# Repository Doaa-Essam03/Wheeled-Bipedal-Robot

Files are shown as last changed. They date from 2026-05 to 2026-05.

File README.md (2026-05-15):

# Two-Wheeled Self-Balancing Wheel-Legged Robot
**Department of Mechatronics Engineering - Control Systems I**

---

## 📖 Project Overview
This project involves the development of a hybrid locomotion system that combines the high maneuverability of wheeled rovers with the terrain adaptability of bipedal kinematics. By integrating two legs with wheeled feet, the robot can perform height adjustments, X-Y planar navigation, and obstacle avoidance while maintaining vertical equilibrium. The dynamic modeling is based heavily on a four-link geometric-dynamic coupling approach, effectively merging a dual-wheel inverted pendulum with a variable-height linkage mechanism.

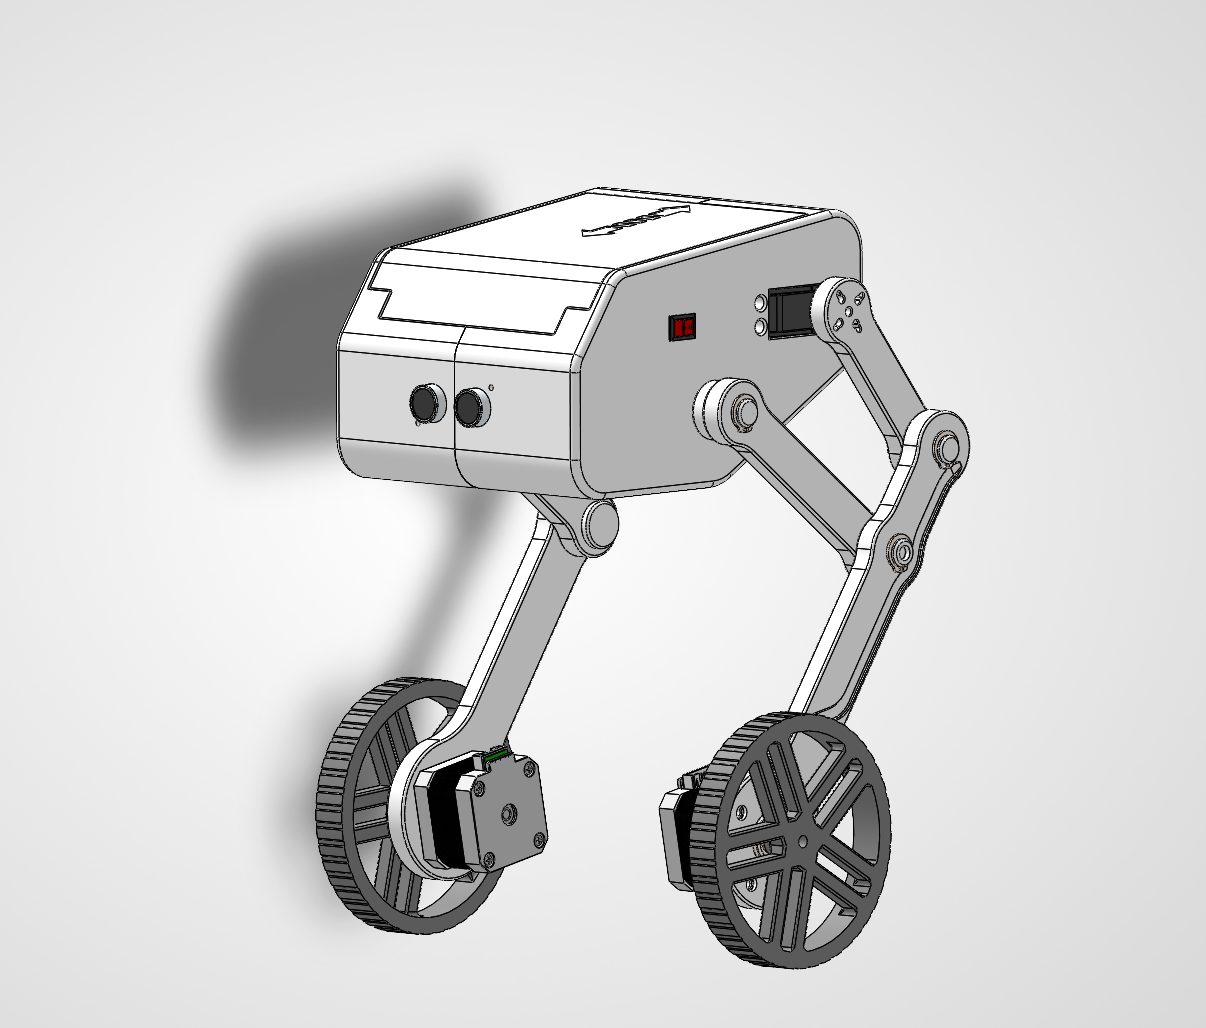
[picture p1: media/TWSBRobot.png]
Assembled Robot

*Figure 1: The fully assembled Two-Wheeled Self-Balancing Wheel-Legged Robot.*

---

## ⚙️ System Architecture
The project is divided into four main engineering pillars:

* **Mechanical Design:** A 2-DOF per leg assembly designed in SolidWorks, optimized for a low Center of Mass (CoM) and minimal inertia. Actuation is handled by NEMA 17 Stepper motors for wheel drive/X-Y motion and Servo motors for leg articulation.
* **Mathematical Modeling:** Derivation of the system's equations of motion, resulting in a non-linear state-space model that decouples the dual-wheel inverted pendulum from the four-link kinematics.
* **Control Engineering:** Implementation of a nested loop control architecture:
    * **Inner Loop:** Proportional-Derivative (PD) control for leg height adjustment and Virtual Model Control (VMC) for joint torque mapping.
    * **Outer Loop:** Linear Quadratic Regulator (LQR) for optimal tilt stabilization and spatial trajectory tracking.
* **Embedded Systems:** Built around an Arduino Nano/ESP32 architecture, featuring real-time sensor fusion using an MPU6050 IMU for attitude estimation. 

---

## 🧠 Control Strategy & Mathematical Modeling
Due to the nonlinear and strongly coupled characteristics of wheeled bipedal robots, developing an accurate mathematical model is critical. 

### State-Space Representation
To design the LQR controller, the system was linearized around the upright equilibrium point ($\theta \approx 0$). 

**4-State Baseline Model (Longitudinal Motion):**
Handles forward/backward displacement and pitch stabilization.

$$X_4 = [x, \dot{x}, \theta, \dot{\theta}]^T$$

**6-State Advanced Model (Spatial Motion):**
Integrates differential drive kinematics to actively command asymmetric torque for yaw (steering) without destabilizing the pitch axis.

$$X_6 = [x, \dot{x}, \theta, \dot{\theta}, \delta, \dot{\delta}]^T$$

**Objective:**
Minimize the cost function $J$ to find the optimal gain matrix $K$, balancing the penalty on pitch deviation against excessive torque demands:
$$J = \int_{0}^{\infty} (X^T Q X + u^T R u) dt$$

### Polynomial Fitting & Real-Time Gain Scheduling
A fundamental challenge of this robot is that its center of mass ($l_w$) and rotational inertia continuously change as the leg linkages flex and extend. Continuously solving the discrete Algebraic Riccati Equation (DARE) for the LQR controller is computationally expensive and would cause severe loop latency on an embedded microcontroller.

To solve this, an offline **Polynomial Gain Scheduling** architecture was developed:
1.  **Offline MATLAB Evaluation:** The optimal feedback gain matrices ($K$) were pre-calculated across the entire operational range of the upper servo angle ($\theta_1$).
2.  **Curve Fitting:** A least-squares fitting algorithm modeled the relationship between $\theta_1$ and each gain value into second-order polynomials:
    $$k_i(\theta_1) = a_i\theta_1^2 + b_i\theta_1 + c_i$$
3.  **Real-Time Execution:** During live operation, the microcontroller simply reads the current servo angle and evaluates these polynomials to instantly update the $K$ matrix coefficients. This reduces complex matrix calculus to basic arithmetic, enabling an ultra-fast control frequency of 200 Hz.

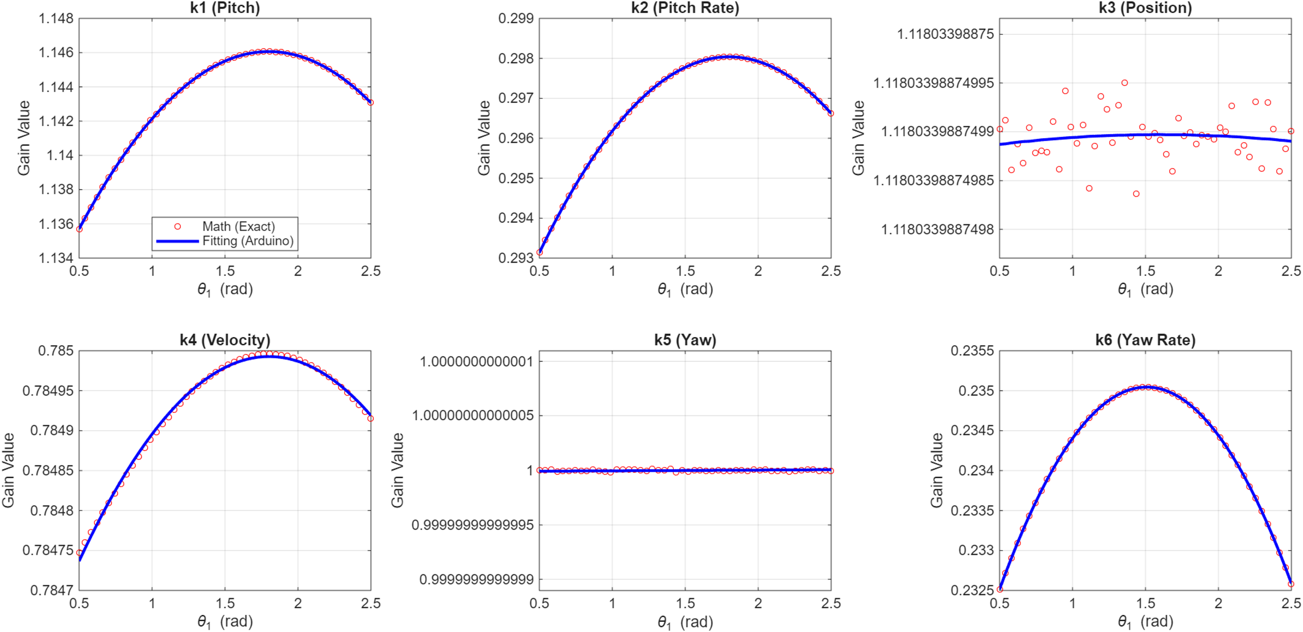
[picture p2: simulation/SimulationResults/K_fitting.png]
Validation of K Matrix Gains

*Figure 2: MATLAB polynomial curve fitting vs. exact mathematical $K$ matrix gains across the operational servo angles.*

---

## 📁 Repository Navigation
* **/hardware:** SolidWorks `.SLDASM` files, 3D printing STL files.
* **/simulation:** `.slx` Simulink models (including Simscape Multibody environments) and MATLAB kinematics/fitting scripts.
* **/firmware:** Source code for the microcontroller (written in C++), featuring I2C MPU6050 drivers, offline polynomial arrays, and the high-frequency LQR/PD control loops.
* **/docs:** Reference papers, the final project report, and the mathematical derivation of the plant.
* **/media:** Videos and pictures of the physical testing.

---

## 🎯 Key Technical Features
* **Dynamic Balancing:** Active rejection of external gravity and impulse forces via continuous LQR state-feedback.
* **Variable Height & Gain Scheduling:** Offline polynomial curve fitting ensures the LQR controller dynamically adapts to shifting inertia and CoM as the robot squats or stands.
* **Virtual Model Control (VMC):** Bridges multi-body mechanics to actuator joint spaces, calculating required support forces without injecting disruptive disturbances into the primary balancing loop.
* **Sim-to-Real Verification:** Validated 3D multi-body pitch stabilization inside a high-fidelity Simscape physical environment prior to hardware deployment.

---

## 👥 Team Members
* **Doaa Essam, Amr Mohamed, Alyaa Mohamed, Abdelrahman Hatem, Esraa Mohamed, Mina Sameh**

### Under supervision of: 
* **Assoc. Prof. Dr. Shuaiby Mohamed**
* **Faculty of Engineering, Assiut University (2025-2026)**

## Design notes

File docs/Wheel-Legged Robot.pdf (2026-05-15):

# Wheel-Legged Robot

## MET 331: Automatic Control 1

## Team Members

Amr Mohamed | Doaa Essam
Abdelrahman Hatem | Esraa Mohamed
Mina Sameh | Alyaa Mohamed

## Supervisor

## Assoc. Prof. Dr. Shuaiby Mohamed

## Mechatronics Engineering Department Faculty of Engineering Assiut University

2025-2026

II

### 1 Table of Contents

1 | Table of Contents | II
2 | Table of Symbols | V

III

IV

Table of Figures

V

### 2 Table of Symbols

Table 1. Parameter definitions of inverted pendulum model.

Symbol | Meaning | Unit
M | Body mass | kg
m | Wheel mass | kg
l | Distance from body center of mass to wheel center | m
r | Wheel radius | m
D | Distance between left and right wheels | m
g | Gravitational acceleration | m/s²
θ, θ̇, θ̈ | Machine pitch angle, angular velocity, angular acceleration | rad, rad/s, rad/s²
T_L, T_R | Driving torque of the wheel | N·m
NL, NR, PL, PR | Force between the body and the wheel in the x and y directions | N
F_L, F_R | Friction between the wheel and the ground | N
xL, xR, ẋL, ẋR, ẍL, ẍR | Wheel displacement, velocity, acceleration | m, m/s, m/s²
ωL, ωR, ω̇L, ω̇R | Wheel rotation angular velocity and acceleration | rad/s, rad/s²
I | Wheel moment of inertia | kg·m²
Jx, Jy, Jz | Moment of inertia of the body around the x, y, z axes | kg·m²
δ, δ̇, δ̈ | Course angle, angular velocity, angular acceleration | rad, rad/s, rad/s²

Table 2. Parameter definitions of the wheel-legged robot model.

Symbol | Meaning | Unit
l1, l2, l3, l23 | Length of the corresponding rod | m
l4 | Distance between the joints | m
l5 | Distance from the intersection point of the upper joint to the lower lever | m
lleg | Pendulum height | m
θ1 | Angle between bar l2 and the horizontal axis | rad
θ2 | Angle between auxiliary connecting rod l4 and l5 | rad
θ3 | Angle between auxiliary connecting rod l5 and l23 | rad
θ4 | Angle between bar l1 and the horizontal axis | rad
θ5 | Angle between bar l23 and the horizontal axis | rad
θ6 | Angle between bar l3 and the horizontal axis | rad
Ldesired | Desired leg length | m
xc2, xc1, xc3, xc23 | Vertical coordinates of the center of mass of the connecting rod | m
L0 | Height of the total center of gravity of the system | m
lw | Height of the center of gravity of the pendulum | m
R | Drive wheel radius | m
mw | Drive wheel mass | kg
mb | Body mass | kg
ml | Pendulum mass | kg
mp | Total system mass | kg
L1 | Distance from center of gravity to wheel axle | m
Iw1 | Drive wheel moment of inertia | kg·m²
Ip1 | Moment of inertia of a pendulum | kg·m²
N | Normal force | N
P | Combined force of gravity and acceleration | N
T | Driving torque | N·m

### 3 Introduction

### 3.1 Evolution of Mobile Robotics The Wheel-Legged Paradigm

For intelligent mobile robots, the Wheel-Legged Robot is dealt with as high maneuverability, easy transformation, and

efficient animal-based design robots. The evolution of these platforms seeks to bridge the gap between the speed of

traditional wheeled rovers and the terrain adaptability of legged variants.

### 3.2 Project Scope and Academic Context

This project enabled us in integrating variable subsystems in one project being such impressive Mechatronic system

enabling. From Mathematical equations, Mechanical design, Embedded system integration, and Control system design,

the scope covers the full lifecycle of mechatronic product development.

### 4 Problem Statement

Developing a unified wheel-legged robot is dealt with as a complex mechatronic struggle where the gap between

theoretical mathematical models and physical embedded hardware often results in poor system performance. The non-

linear multi-body dynamics inherent in combining a four-bar linkage with an inverted pendulum create significant

computational bottlenecks for standard embedded controllers.

This project enabled us in overcoming the difficulty of synchronizing mechanical link dynamics with real-time control

algorithms being a fully integrated mechatronic achievement. From mechanical design complexities, mathematical

modeling errors, embedded integration hurdles, and control system instability.

### 5 Project Objectives

For achieving high maneuverability and stability, this project aims in developing advanced hybrid control systems. This

requires structural optimization of the linkage mechanisms, mathematical optimization through polynomial fitting to

handle dynamic shifts, and scaling the control architecture to manage varied actuators.

This project enabled us in creating accurate mathematical models being such a precise mechatronic integration. From

LQR for balance, PD for height control, and Fitting Techniques for real-time CoM prediction with considering applying

these strategies in a real-world plant.

### 6 Mechatronic System Design

### 6.1 Mathematical Modeling for the system

Treating physical plant as two subsystems: height subsystem or four bar linkage to model the variation in height and leg

mechanism, and inverted pendulum subsystem to model the balancing function of the robot and its motion.

### 6.2 Control System Configuration

Based on mathematical model made and out understanding of the physical functions needed, we made the control

strategy to be in two systems: PD control to manage height, LQR control to manage balance and motion.

### 6.3 Physical system design (Mechanical)

Here we created the physical plant to be established in real-world. The plant design must fit configurations made in

mathematical model from masses and dimensions.

### 6.4 Embedded Hardware in Robot

The physical plant to be actuated we need actuators to do the functions needed, sensors to close the control loop, and

controller itself to manage all that.

### 6.5 Mechanical Design

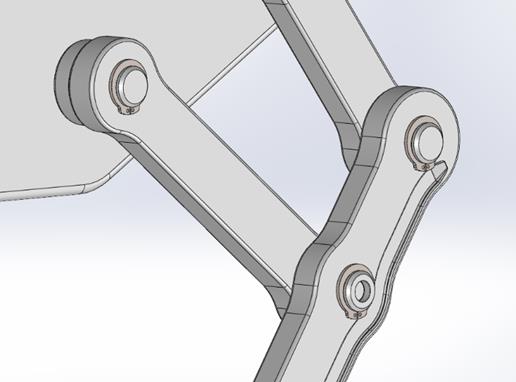
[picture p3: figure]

Figure 1 linkage fixdiation

The design is made mainly to be easy in manufacturing and assembly.
From selecting 3D printed PLA to be the material used, we customized the design on it.
The design is easy in assembly by using snap-rings, interference fit assembly, and easy pin usage with respect of suitable dimensions.

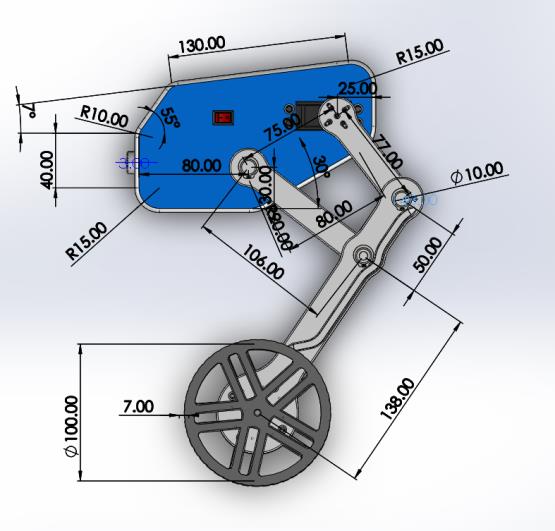
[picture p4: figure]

Figure 2 Side View

Figure 4 3d printed part

Figure 3 side view of linkage

Figure 5 Assembled robot

Figure 6 Exploded view

Also for wire management, we made a slot in stepper-motor’s link to act like a duct for wires to manage in.

In wheel, it’s critical area where we need to decrease friction between wheel and link, and increase friction in suitable area between wheel and ground to keep balance and stable and move right.
We designed the wheel to have a good friction surface with ground, ribs are made to avoid stresses on hip and make two direction of reaction torques from ground to wheel what make a passive balance.

Also considered bearing assembly between wheel and motor’s shaft to keep smooth motion.

### 6.6 Electronic Hardware and Sensor Integration

The robot hardware consists of sensing, control, and actuation components integrated together to achieve self-

balancing operation.

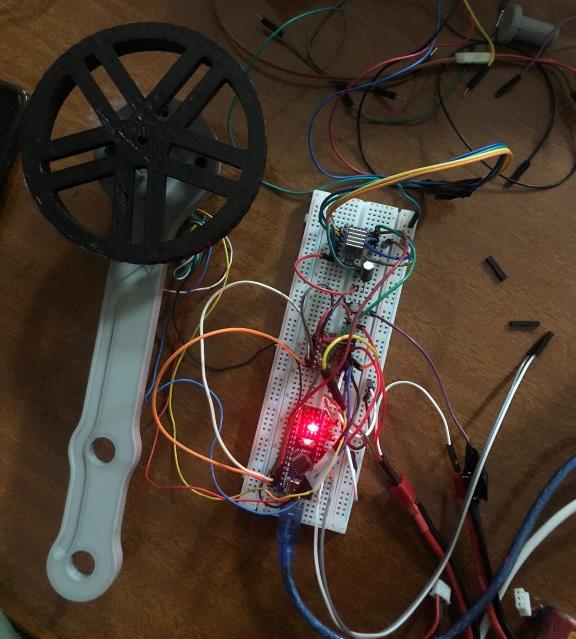
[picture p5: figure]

Figure 7 Testing stepper motor

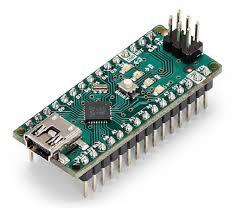
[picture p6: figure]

### 6.6.1 Central Processing Unit (ESP32)

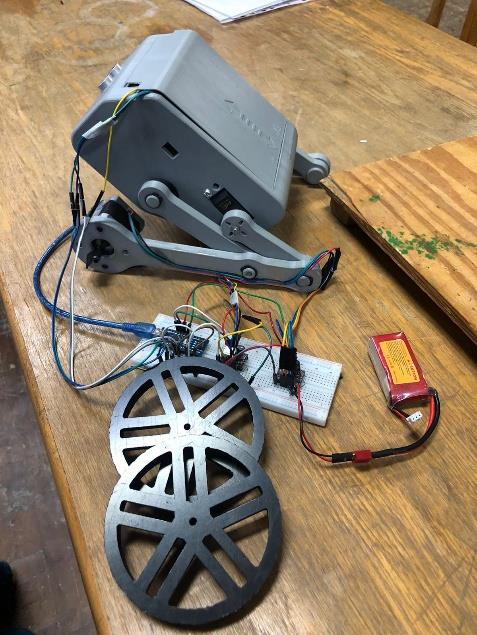
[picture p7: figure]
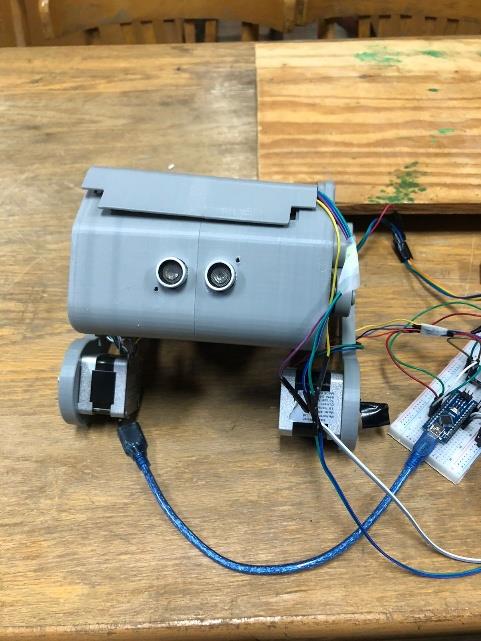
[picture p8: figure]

The main controller used in the system is the Arduino Nano, which is responsible for

processing sensor data and generating control signals for the motors.

An ESP32 module was also considered for future development to provide wireless

communication, remote monitoring, and real-time data transmission capabilities.

### 6.6.2 Attitude Estimation (MPU6050 IMU & Filtering)

The robot uses the MPU6050 inertial measurement unit to measure the robot

orientation and angular velocity.

The sensor communicates with the Arduino Nano using the I2C protocol

through the SDA and SCL pins.

The MPU6050 sensor is connected to the Arduino Nano using the I2C

communication protocol. The SDA pin of the MPU6050 is connected to pin A4

of the Arduino Nano, while the SCL pin is connected to pin A5. The sensor is

powered using the 5V and GND pins of the Arduino. Through this connection,

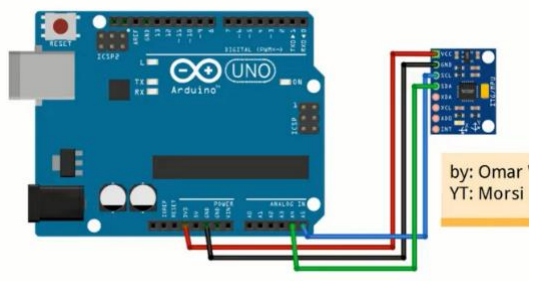
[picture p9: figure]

Figure 8 MPU wiring

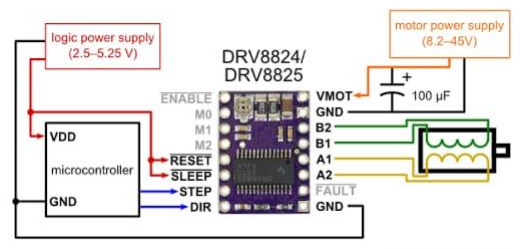
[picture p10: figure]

Figure 9 stepper driver wiring the microcontroller continuously receives accelerometer and gyroscope measurements required for estimating the

robot orientation and angular velocity

### 6.6.3 Ultrasonic

Additionally, an ultrasonic sensor was prepared for future implementation in obstacle detection and

environmental interaction. The sensor has not yet been integrated into the software because the current stage of

the project focuses mainly on achieving stable balancing performance.

### 6.6.4 Actuation System (Stepper Motors & Servos)

### 6.6.4.1 Stepper motors

Two stepper motors are used as the main actuation system for balancing

and movement. Each motor is driven using a DRV8825 Stepper Motor

Driver driver module, which receives STEP and DIR signals from the

microcontroller to control motor speed and rotation direction with high

precision.

### 6.6.4.2 Servo motors

The system also includes two servo motors intended for adjusting the robot leg configuration and varying the

effective pendulum length during operation. However, in the current implementation, the leg length is assumed

to be fixed; therefore, the servo motors are not yet integrated into the code in arduino .

### 6.6.5 Power Management (LiPo Battery Weight Reduction)

A high-discharge Lithium-Polymer (LiPo) battery pack was selected to power the system instead of traditional heavy

batteries, due to its superior energy density and lightweight profile. This choice minimized the global weight of the

prototype and successfully delivered the high current spikes required by the NEMA 17 stepper motors during rapid

balancing corrections, while placing it at the bottom of the chassis base successfully lowered the center of mass to

enhance structural stability.

### 7 Mathematical Modelling

The wheeled bipedal robot is a complex nonlinear multiple-input multiple-output system, which regards the robot as a

combination of left and right legs, left and right wheels, plus the body, and left and right symmetry, so an idealized

setting can be made.

The robotic dynamic model is decomposed into wheel motion and leg motion. The wheel subsystem, responsible for

linear locomotion and steering, is simplified as a two-wheel inverted pendulum model. The leg subsystem employs a

four-bar linkage mechanism to achieve jumping, full-body height adjustment, and adaptive locomotion on uneven

terrain. By focusing on analyzing the dynamic model of the four-bar linkage motion, the originally coupled complex

model is streamlined. As shown in Figure 1, this decoupling strategy simplifies the design process while retaining critical

functionalities, thus enabling efficient control of the robot’s hybrid mobility modes.

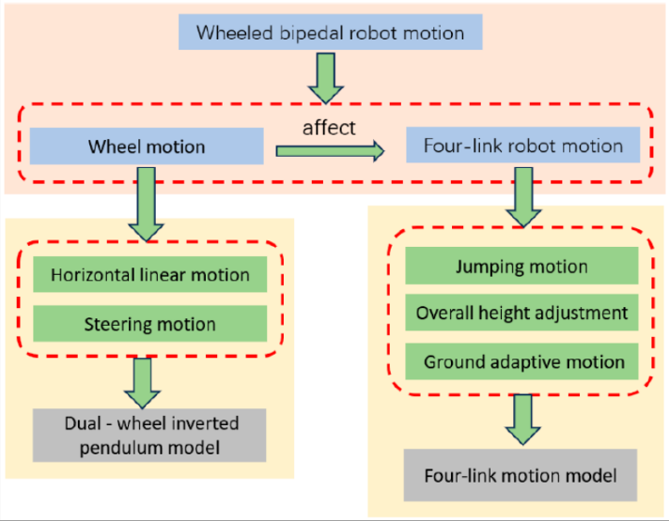
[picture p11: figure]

Figure 10 modeling systems

### 7.1 Dual-Wheel Inverted Pendulum Model

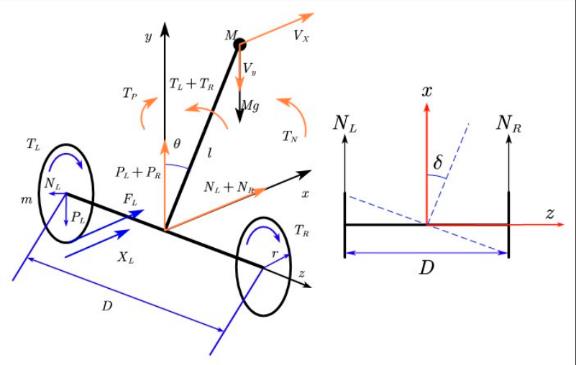
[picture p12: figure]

The mass of the body is equivalently concentrated in the position of the center of mass. Ignoring the effect of the leg motion on the wheeled movement and the mass of the four links, the driving wheels are in non-slip rolling friction with the ground. Therefore, the four-link wheel-legged robot can be equivalently simplified into a two-wheeled inverted pendulum model with variable rod length , see Figure 2 and Table 1.

### 7.1.1 The equations of Inverted Pendulum

### 7.1.1.1 Planar Linearization and Baseline Dynamics

To design a linear optimal controller such as the Linear Quadratic Regulator (LQR), the highly non-linear equations of motion derived via the Euler-Lagrange framework must be linearized around the upright equilibrium point. When the pitch inclination of the main body ($\theta$) is small (θ ≈ 0$), the small-angle approximation can be applied safely. Under these assumptions, higher-order differential terms are neglected, and the trigonometric variables are linearized as follows

Figure 11 Inverted Pendulum Model

cos θ ≈ 1, sin θ ≈ θ, θ

2̇ ≈ 0

Applying these conditions to the continuous planar dynamics yields the coupled, linearized differential equations governing longitudinal displacement (x) and body pitch (θ) [1]:

(M + 2m +

2Iw
r

2

) ẍ=

TL + TR
r

− Mlθ̈

(Jz + Ml

2

)θ̈= Mglθ − Mlẍ− (TL + TR)

These coupled relations serve as the direct mathematical basis for the 4-state state-space block

(X4 = [x, ẋ, θ, θ̇]

T
)

constructed within the MathWorks Simulink modeling workspace to evaluate initial straight-line balancing performance.

### 7.1.1.2 Steering Kinematics and Yaw Modeling

To achieve full 3D planar mobility, differential steering capabilities must be integrated alongside the longitudinal balancing routines. By sorting the mechanical equations of constraint across the transverse horizontal frame, the uncoupled dynamic equation governing the steering yaw angle ($δ$) is formulated as follows [1]:

δ̈=

TL − TR
r (mD +

ID
r

2 +

2Jy
D

)

This yaw relation is mathematically superimposed over the planar balancing matrix to build out the full 6-state spatial LQR vector ($X6 = [x, ẋ, θ, θ̇

, δ, δ̇]

T
$). Within Simulink, this decoupled torque relationship (ΔT = TL − TR$) is utilized by the controller to actively adjust steering headings without injecting unstable oscillations into the main pitch axis ($θ$).

Inverted pendulum model in Simulink

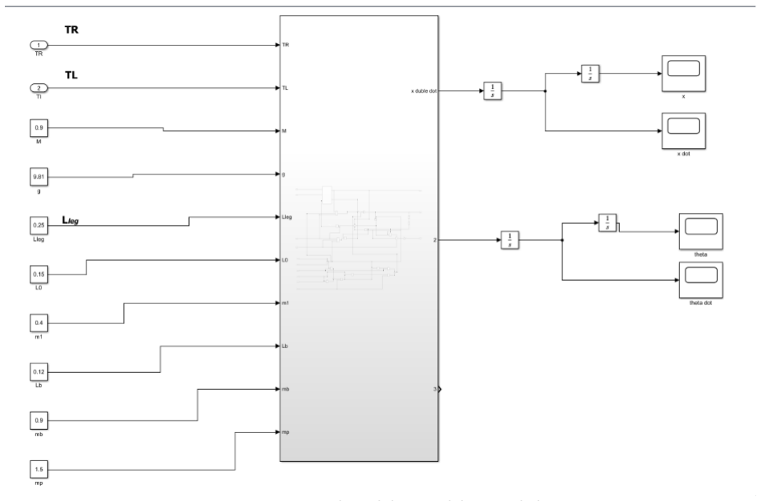
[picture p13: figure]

Figure12 Inverted pendulum model in Simulink

### 7.1.2 Four-Link Motion Model

The whole machine is symmetrical on the left and right, the kinematics of the four-link structure of the left leg are analyzed in detail see figure , and the relevant parameters are illustrated in Table 2 .

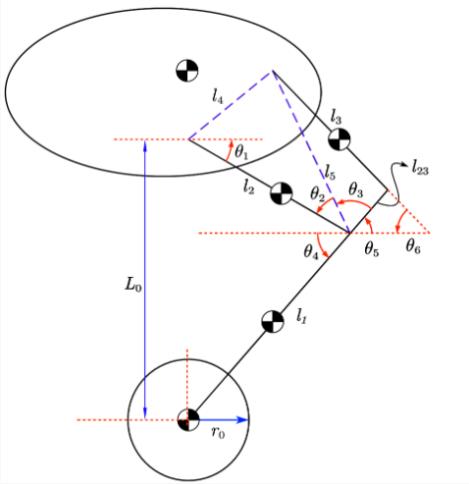
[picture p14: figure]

Figure 12 Four-Link Motion Model

### 7.1.2.1 The equations of Four-Link Mechanism

Given the instantaneous command angle of the joint servo motor θ1, the secondary linkage parameters (θ2, θ3, θ4) and

the final effective leg length ($l_{leg}$) are computed explicitly as follows:

l5 = √l2
2 + l4

2 − 2 ⋅ l2 ⋅ l4 ⋅ cos (θ1 +

π
4

)

θ2 = arcsin(
l4 ⋅ sin (θ1 +

π
4

)

l5

)

θ3 = arccos (
l23

2 + l5

2 − l3
2
2 ⋅ l23 ⋅ l5

)

θ4 = π − θ1 − θ2 − θlleg = l2 ⋅ sin(θ1

) + l1 ⋅ sin(θ4)

### 7.1.2.2 Inverse Kinematics (Leg Length to Angle)

When managing height tracking commands, the target leg length (l{leg}) is transformed back into the required actuator

servo angle (θ1) along with companion configurations (θ5, θ6) via the following inverted expressions:

θ1 = arcsin (

lleg

2 + l2 2 − l1
2
2 ⋅ lleg ⋅ l2

)

θ5 = π − θ4

θ6 = arcsin (
l5 ⋅ sin( 3

)
l3

) − θ4

### 7.1.2.3 Center of Gravity Offset (lw)

The overall vertical center of mass displacement (lw) of the mechanical assembly relative to the wheel rotational hub is obtained directly by subtracting the linkage mass weighted average (Lo) from the total computed leg height:

lw = lleg − L0

Where L0 represents the composite geometric center of gravity distribution across the linkage components (m1, m2, m3, m23):

L0 =

m1 ⋅ xc1 + m2 ⋅ xc2 + m3 ⋅ xc3 + m23 ⋅ xc23 m1 + m2 + m3 + m23

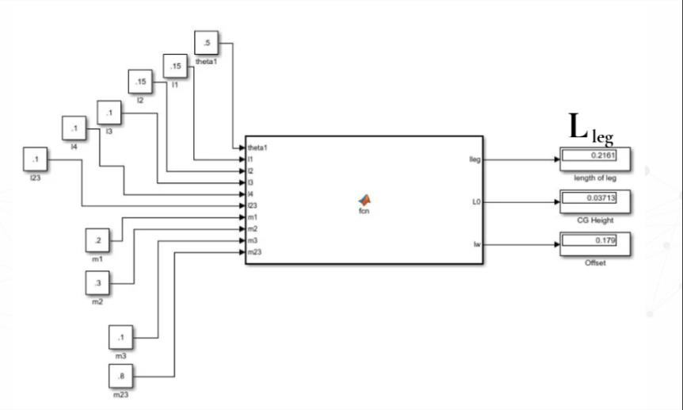
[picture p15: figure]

### 8 Control Strategy

### 8.1 PD control

PD control is used to calculate the external force F0 that needs to be applied on the joint motor. Omitting the I term can

avoid the situation of integral saturation overshooting and improve the dynamic response speed, which is suitable for

highly dynamic scenarios. The integral term will accumulate noise or high-frequency interference, which will lead to

jitter of the control signal, while the differential term has a natural suppression effect on high-frequency noise, and PD

control is more anti-interference.

### 8.1.1 Error Formulation and Controller Optimization [1]

The height controller monitors the instantaneous offset between the calculated leg length (lleg) and the target setpoint (L_{desired}). The geometric tracking error (e)is defined as [1]:

e = lleg + Ldesired

Using this error signal, the restorative control effort (τPID)is processed via a PD loop to drive the vertical tracking error to zero :

τPID = Kpe + Kd

de
dt

### 8.1.2 Gravity Feedforward Compensation [1]

The mass of the physical robot assembly serves as a continuous constant load on the articulated joint actuators. The

vertical ground support force required to hold the chassis is proportional to the total gravitational force (mg). However,

due to the articulation angle of the four-bar linkages, the actual torque seen at the link joint is modulated by its

geometric position. The localized joint-angle effect is captured by introducing a continuous gravity compensation

component (τgravity):

τgravity = mg cos(θ1)

Where cos(θ1

)reflects the instantaneous rotation angle of the joint relative to the gravitational vector. Combining the

dynamic PD response alongside this static feedforward torque yields the final required external joint force command F0

F0 = τgravity + τPID

### 8.2 Virtual Model Control (VMC) and Joint Torque Mapping [1]

To implement the calculated spatial force commands (F0$) using physical hardware, Virtual Model Control (VMC) is

utilized. VMC creates a mathematical bridge between physical multi-body mechanics and actuator joint spaces. This

architecture assumes an ideal "virtual model" (such as a structural spring-damper suspension) exists between the main

chassis frame and the driving wheel hub,

### 8.2.1 Jacobian Formulation and Force Translation [1]

Translating the operational force F0 into a concrete joint motor torque Tjoint requires evaluating the geometric

constraints of the closed four-bar linkage mechanism. By transforming the link angles and tracking segment lengths, the

continuous system mapping is resolved using a localized scalar element of the system Jacobian matrix (J) [1]:

J = l2 cos(θ1

) + l1 cos(θ1 + α + β)

The computed external force (F0) acting from the end-effector endpoint serves as the fundamental input variable for the

virtual model. By applying the principle of virtual work, the geometric parameters and kinematic configurations are

mapped cleanly to the physical actuator via the Jacobian scalar :

Tjoint = F0 J

This VMC framework operates in parallel with the high-speed wheel LQR tracking loops. It allows the ESP32

microcontroller to execute smooth, low-latency crouching, standing, and active landing maneuvers on the physical

hardware without injecting disruptive force disturbances into the primary self-balancing control loops.

### 8.2.2 PD control & Four bar linkage Model in Simulink

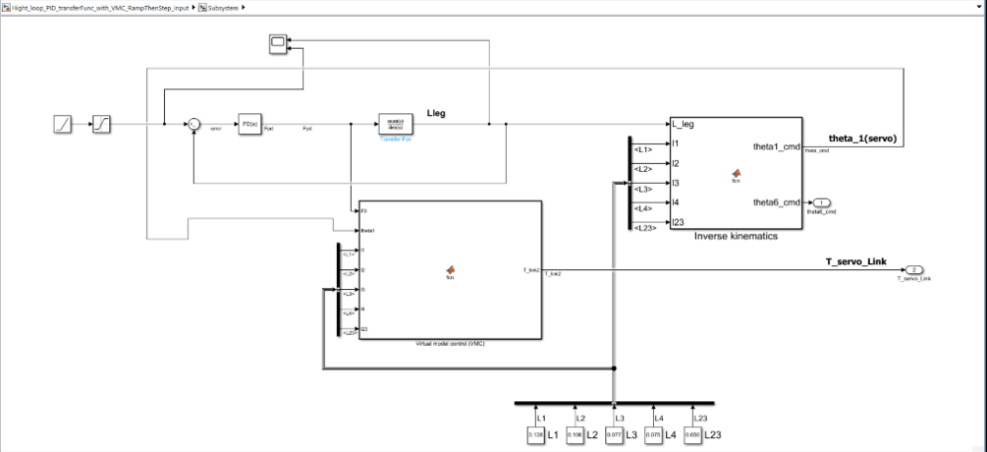
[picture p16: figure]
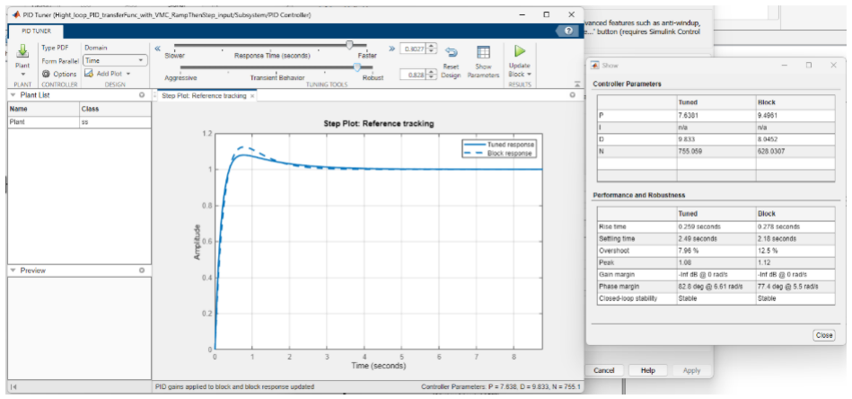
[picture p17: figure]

Figure 13 PD Response

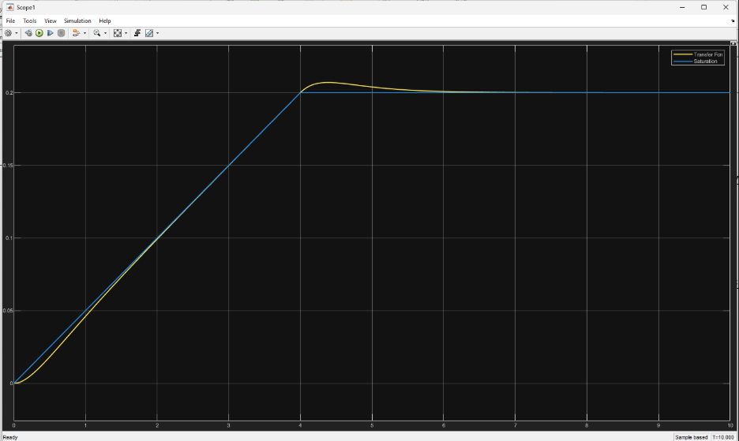
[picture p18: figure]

Figure 14 PD response with ramp mixed step input

### 8.3 LQR with Dynamic Modeling & State-Space Expansion

Due to the nonlinear and strongly coupled characteristics of wheeled bipedal robots, developing an accurate

mathematical model is critical for effective control. The fundamental challenge of the TWSBR is that its center of mass

(COM) and rotational inertia change continuously as the leg linkages flex and extend. To achieve robust balancing and

trajectory tracking, the dynamic equations were derived using the Euler-Lagrange formalism and subsequently linearized

around the upright equilibrium point to form the state-space representation
Ẋ = AX + Bu

Recognizing the need for both longitudinal stability and spatial maneuverability, the control architecture was

incrementally expanded from a planar 4-state model to a comprehensive 6-state model and tested inside MathWorks

Simulink.

### 8.3.1 Baseline 4-State Longitudinal Model (x, ẋ, θ, θ̇)

The initial control framework treated the robot as a variable-length two-wheeled inverted pendulum restricted to purely

longitudinal (forward and backward) motion. The system dynamics were captured using a 4-dimensional State Vector :

X4 = [x ẋ θ θ̇]

T

where xand ẋ represent the longitudinal displacement and velocity of the wheel axle, while θ and θ̇ denote the pitch

angle and pitch angular velocity of the main body, respectively. In this planar configuration, the control input u was

defined as the total symmetric torque applied to both wheels, u = TL + TR

The Linear Quadratic Regulator (LQR) was designed to minimize the cost function J = ∫ (X

TQX + u

TRu)dt ∞
0

, where the

state weight matrix Q heavily penalized deviations in the pitch angle to prevent tipping, and the control weight matrix R

restricted excessive torque demands that could saturate the stepper motors.

This configuration was modeled in Simulink utilizing the native State-Space block to evaluate baseline stabilization and

straight-line displacement tracking.

### 8.3.2 Advanced 6-State Spatial Model (Integration of Yaw δ, δ̇)

While the 4-state model successfully stabilized the robot against gravity, real-world navigation requires active steering.

The model was therefore expanded into a 6-state spatial vector to incorporate differential drive kinematics:

X6 = [x ẋ θ θ̇ δ δ̇]

T

Here, δ and δ̇represent the yaw (heading) angle and yaw rate. To control this expanded system, the input vector was

separated into independent left and right wheel torques:

u = [

TL
TR

]

This decoupling allows the LQR controller to actively command asymmetric torque (TL ≠ TR) to induce a turning

moment around the Z-axis, while simultaneously maintaining the symmetric torque required to keep the inverted

pendulum upright.

This advanced configuration was fully implemented inside a 6-state Simulink block diagram. Virtual reference-tracking

verification was conducted by feeding targeted coordinate trajectories into the controller. The resulting response curves

verified that the 6-state system could successfully execute full planar trajectory following and waypoint target capture

without destabilizing the pitch axis.

Figure 15: LQR with 4

Figure 16 : LQR with 6

### 8.4 Look-up Polynomial Fitting & LQR Gain Scheduling

A critical limitation in embedded mechatronics is the computational bottleneck of solving complex mathematical models

in real-time. Calculating the optimal LQR feedback matrix K requires solving the discrete Algebraic Riccati Equation

DARE. Because the A and B matrices in our state-space model are heavily dependent on the time-varying linkage angle

(θ1

) the optimal K matrix must also change dynamically. However, continuously solving the DARE on an ESP32

microcontroller at a high control frequency (e.g., 200 Hz) would cause severe loop latency. To bypass this, an offline

gain-scheduling architecture was developed.

### 8.4.1 Offline MATLAB Curve Fitting for Kinematics

To eliminate real-time computational overhead, the non-linear geometric and optimal control calculations were shifted

offline. A MATLAB script was developed to sweep through the entire operational range of the upper servo angle

θ1 ∈ [0.5,1.25] rad . For each discrete angular increment, MATLAB evaluated the exact closed-form vector loops to

determine the leg length (lleg) and the vertical center of gravity offset (lw). The script then generated the localized A

and B state-space matrices and solved the DARE to extract the optimal K matrix for that specific posture.

Finally, a least-squares curve fitting algorithm was applied to model the relationship between θ1 and each specific gain

value kiwithin the K matrix. The resulting approximations took the form of second-order polynomials:

ki

(θ1

) = aiθ1

2 + biθ1 + ci

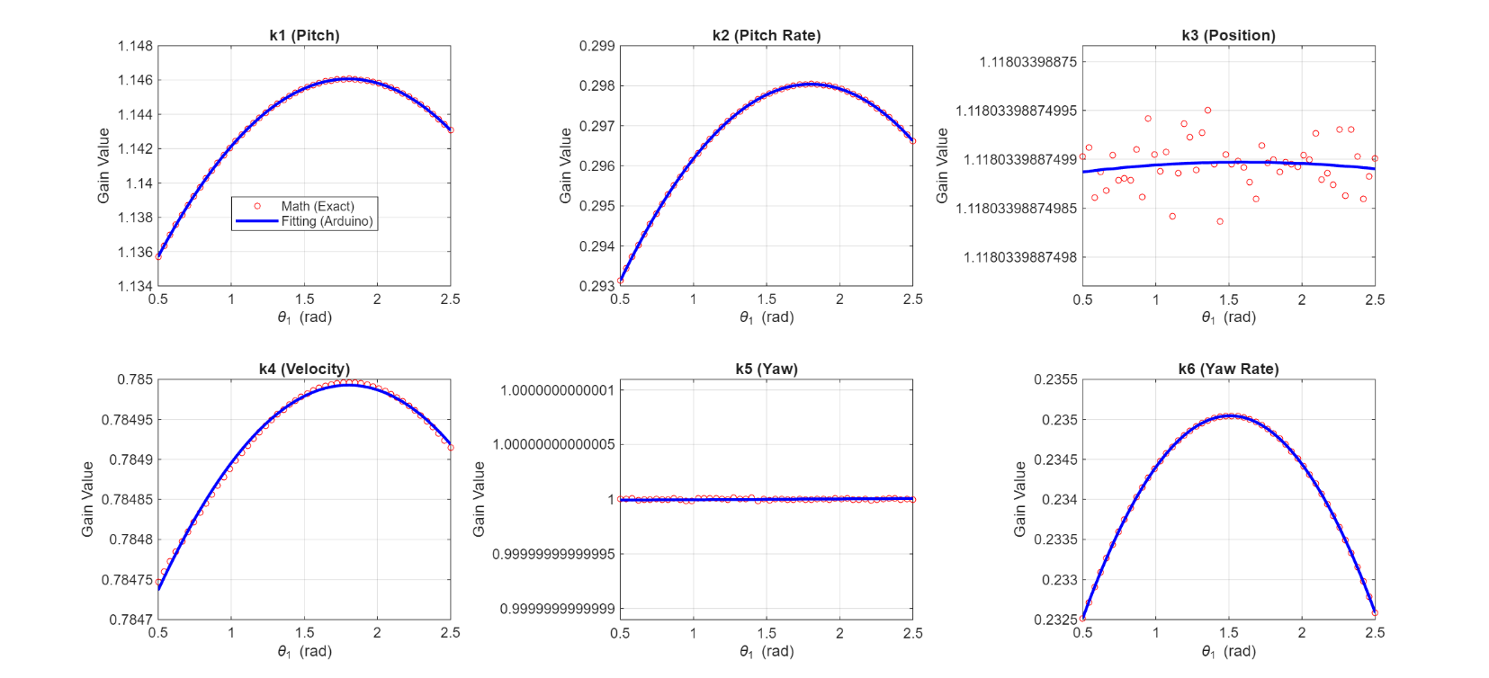
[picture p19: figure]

Figure 17 validation k matrix gains

### 8.4.2 Real-Time LQR Matrix Adjustment

During live operation, the ESP32 executes a highly optimized gain-scheduling routine. By reading the current servo angle

θ1, the microcontroller evaluates the pre-calculated polynomials to instantly update the K matrix coefficients. This approach reduces the complex matrix calculus down to a few basic floating-point multiplications and additions per cycle.

Consequently, the TWSBR seamlessly scales its control authority, applying stiffer gains when standing tall and softer

gains when crouched low—while maintaining an ultra-fast control loop iteration time that prevents instability.

### 9 Simulation and Experimental Results

### 9.1 Simscape Multi-Body Simulation Environment

### 9.1.1 CAD Integration and Virtual Physics Setup

To validate the control algorithms before hardware deployment, a Simscape simulation environment was established.

Rather than importing the highly detailed manufacturing CAD, a simplified CAD assembly was utilized to identify the

primary components, focusing strictly on accurate mass distribution, inertia tensors, and critical dimensions. A global

ground reference was established, and the robot model was linked using appropriate physical joints. This ensured the

virtual model reacted physically accurately to the simulated ground and spatial environment, properly respecting the

laws of inertia, joint friction, and gravity.

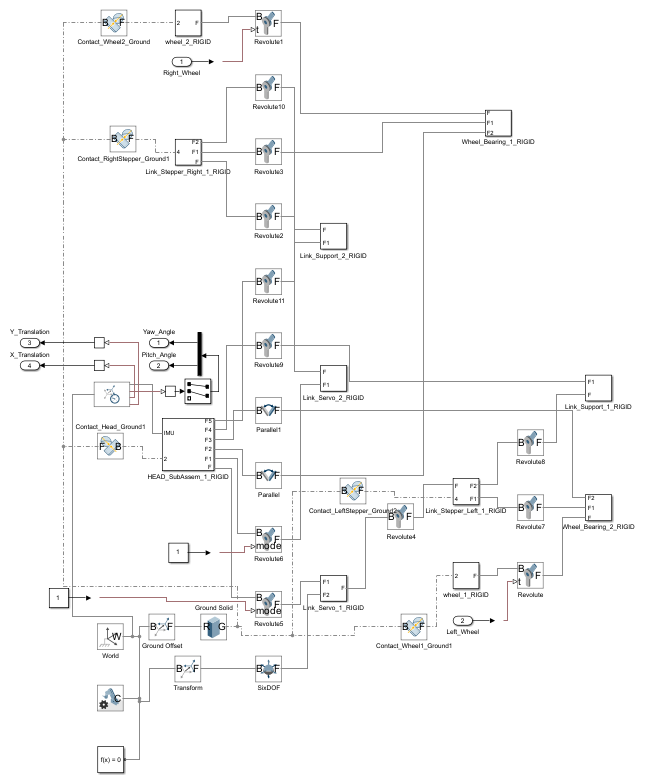
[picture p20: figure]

Figure 18 simscape model

### 9.2 Control Verification

Transitioning directly from mathematical theory to physical hardware carries a high risk of catastrophic failure and

hardware damage. To mitigate this, a high-fidelity virtual environment was constructed by importing the SolidWorks

CAD assembly into MathWorks Simscape Multibody. This setup captures actual material densities, moments of inertia,

and real physical joints, serving as an intermediate stage between ideal block-diagram state-space simulations and

physical reality.

Static Pitch Stabilization (Constant θ1)

The initial simulation phase inside the Simscape physical environment focused entirely on the robot's primary survival

mechanism: active self-balancing. For this verification stage, the servo angle $\theta_1$ was held at a constant value,

fixing the physical four-bar linkages in place. The control loop was structured around feedback sensing blocks acting as

an ideal Inertial Measurement Unit (IMU).In this phase, the LQR tuning process concentrated heavily on the pitch

($\theta$) and pitch rate ($\dot{\theta}$) states to handle balance stabilization. The Simscape model layout integrated

sensory feedback blocks, a closed-loop LQR matrix mixer, and physical rotational actuators on the wheel hubs. The

simulation confirmed that the derived control framework successfully suppressed gravitational tilt errors, achieving

rock-solid upright balance. The collected data plotting curves demonstrated clean convergence back to the zero-pitch

vertical axis following external impulse disturbances.

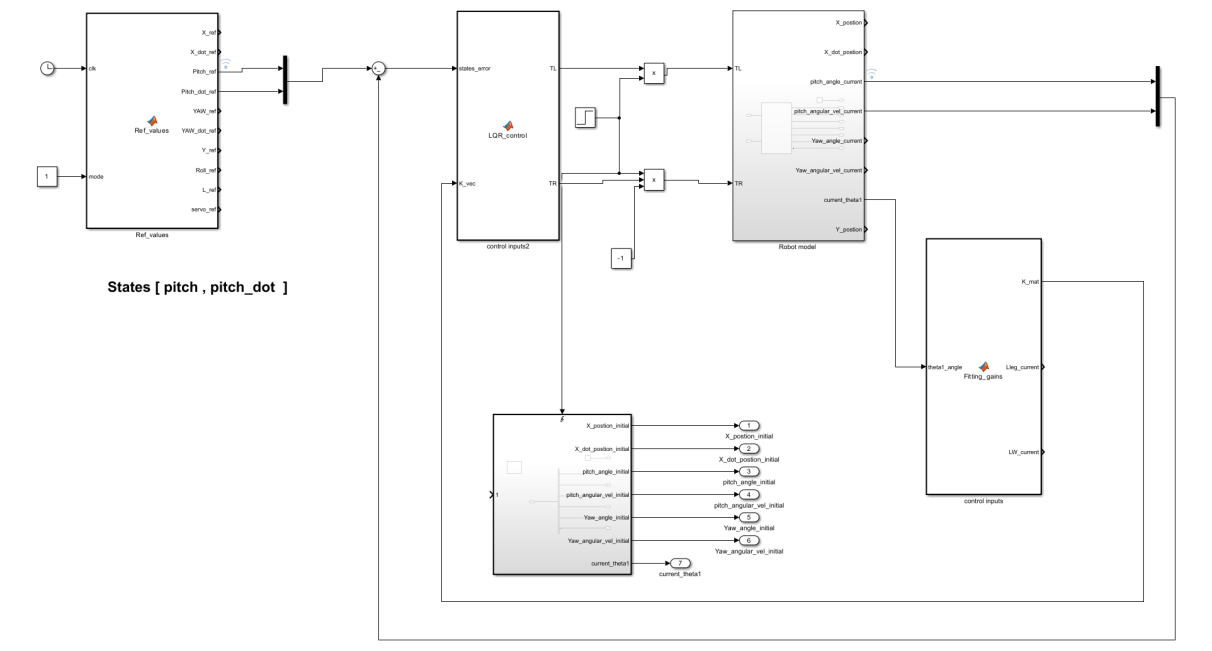
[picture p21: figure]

Figure 19 simulink model with simscape multibody

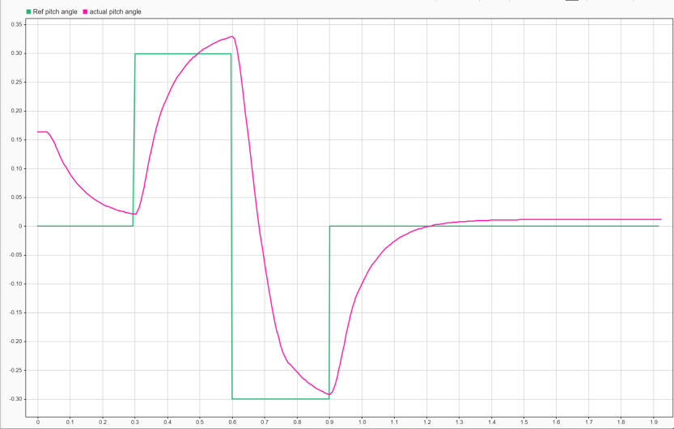
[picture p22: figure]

Figure 20 pitch angle vs Ref Pitch with time

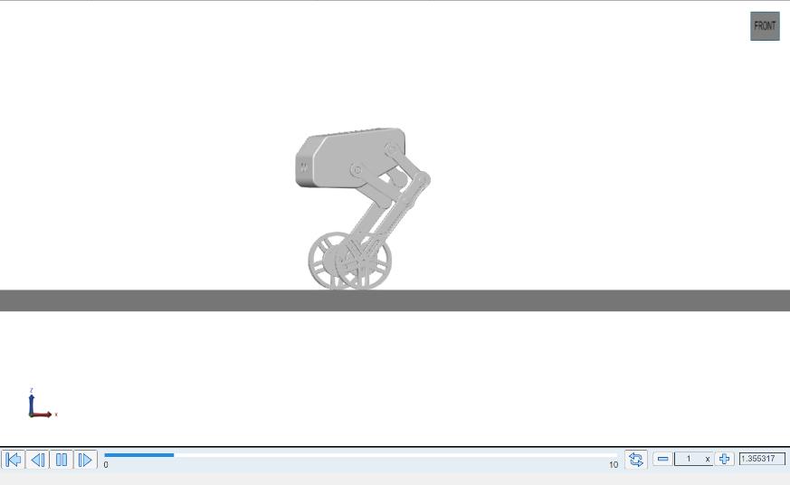
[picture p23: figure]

Figure 21 simscape balaning on 0 rad

### 10 Discussion

The integration of a hybrid control architecture—combining a 4-state and 6-state Linear Quadratic Regulator (LQR) for

planar balance and steering tracking alongside a Proportional-Derivative (PD) loop governed by Virtual Model Control

(VMC) for height adjustments—successfully met the stability and mobility constraints of the Two-Wheeled Self-

Balancing Wheel-Legged Robot (TWSBR). Evaluating these strategies within MathWorks Simulink and Simscape

Multibody provided critical engineering insights into the relationship between theoretical design and embedded

execution.

### 10.1 Computational Efficiency of Polynomial Gain Scheduling

A primary hurdle in wheel-legged robotics is the continuous shift in the physical plant behavior; as the four-bar linkage

alters the stance height, the system's center of mass (lw)and rotational inertia (Ip) vary non-linearly. Standard LQR

control over variable configurations requires continuously solving the computationally expensive discrete Algebraic

Riccati Equation (DARE), an operation that would paralyze the loop frequency of an embedded microcontroller like the

ESP32.

The offline MATLAB sweeping pipeline completely bypassed this bottleneck. By curve-fitting the optimal feedback gain

matrices (K) into analytical second-order polynomials (ki

(θ1

) = aiθ1

2 + biθ1 + ci
) mapped directly to the joint angle,

the real-time execution constraint was reduced to basic floating-point arithmetic. This approach allowed the ESP32

firmware to maintain an ultra-fast, deterministic control frequency of 200 Hz, preserving control authority and avoiding

the loop latencies that induce catastrophic structural oscillation.

### 10.2 Multi-Environment Simulation and Control Verification

The verification roadmap proved that isolating different control objectives across specialized virtual testing grounds is a

highly reliable prototyping pipeline:

1. High-Fidelity Physical Testing (Simscape Multibody): Testing inside Simscape focused strictly on the core

survival layer: pitch stabilization (θ, ̇{θ}). Because Simscape maps true 3D CAD material profiles, contact

frictions, and multi-body constraints, achieving reliable vertical balancing here provided validation that the

mathematical linearization assumptions (cos θ ≈, sin θ ≈ θ were robust against real-world gravity vectors and

actuator response latencies.

2. Numerical State-Space Tracking (Simulink Workspace): Once pitch balancing was validated under physical

constraints, the unlocked 4-state and expanded 6-state models were safely evaluated inside standard Simulink

block-diagram workspaces. Testing coordinate target capture and path-following response curves numerically

demonstrated that the LQR matrix could multiplex asymmetric wheel torques(TL ≠ TR) to negotiate tight

turning radii (δ) without injecting disruptive kinetic energy back into the unstable pitch axis.

### 10.3 Limitations and Future Structural Improvements

While the virtual models achieved high tracking accuracy, several non-ideal physical factors remain unaddressed. The

presence of unmodeled backlash in the physical geared actuators and localized wheel slip under rapid yaw accelerations can degrade pure state feedback tracking over prolonged operations. To eliminate these issues in future hardware

iterations, incorporating an active feedforward friction compensation loop alongside a Kalman Filter to blend the wheel

encoder data with the MPU6050 IMU telemetry will significantly increase spatial tracking robustness over low-traction

operational surfaces.

### 11 Conclusion

This project successfully designed, modeled, and verified an agile, variable-height Two-Wheeled Self-Balancing Wheel-

Legged Robot. By bridging the gap between theoretical multi-body multi-state matrices and embedded hardware

limitations, an efficient mechatronic platform was achieved.

The implementation of an offline polynomial gain-scheduling pipeline provided a highly scalable solution to the time-

varying dynamics caused by the changing configurations of the four-bar linkage mechanism. Isolating the complex

control objectives into specialized testing tiers—evaluating full 3D multi-body pitch stabilization within high-fidelity

Simscape environments, alongside full 4-state and 6-state target-following tracking trajectories using Simulink State-

Space blocks—provided rigorous mathematical and physical assurance.

The hybrid combination of LQR balancing stability, PD height tracking flexibility, and Virtual Model Control (VMC) joint

allocation proved to be an ideal control strategy for wheel-legged architectures. Ultimately, this research provides a

lightweight, computationally highly optimized, and structurally responsive framework that establishes a robust

foundation for future autonomous navigation and highly dynamic mobile robotic maneuvers.

### 12 References

- Design and Control of a Wheeled Bipedal Robot Based on Hybrid Linear Quadratic Regulator and Proportional-

Derivative Control, School of Mechanical and Automotive Engineering, Shanghai University of Engineering Science,

Shanghai, Yanling Tian and Zheng Chen, 2025

- https://youtu.be/rpD8mo0Jbuc?si=x847OHViFeFNNdov

### 13 Appendices

### 13.1 Appendix A: Low-Level Hardware Diagnostics and Unit Testing Scripts

- A.1: MPU6050 Inertial Measurement Unit (IMU) Telemetry Diagnostics
- #include "I2Cdev.h"
- #include "MPU6050_6Axis_MotionApps20.h"
•
- #if I2CDEV_IMPLEMENTATION == I2CDEV_ARDUINO_WIRE
- #include "Wire.h"
- #endif
•
- MPU6050 mpu;
•
- bool dmpReady = false;
- uint8_t devStatus;
- uint16_t packetSize;
- uint8_t fifoBuffer[64];
•
- Quaternion q;
- VectorInt16 gy;
- VectorFloat gravity;
- float ypr[3];
•
- void setup() {
- Wire.begin();
- Wire.setClock(400000);
•
- Serial.begin(115200);
•
- mpu.initialize();
•
- Serial.println(mpu.testConnection() ? "MPU6050 Connected" : "MPU6050 Connection Failed");
•
- devStatus = mpu.dmpInitialize();
•
- mpu.setXGyroOffset(220);
- mpu.setYGyroOffset(76);
- mpu.setZGyroOffset(-85);
- mpu.setZAccelOffset(1788);
•
- if (devStatus == 0) {
•
- mpu.CalibrateAccel(6);
- mpu.CalibrateGyro(6);
•
- mpu.setDMPEnabled(true);
•

- dmpReady = true;
•
- packetSize = mpu.dmpGetFIFOPacketSize();
•
- Serial.println("DMP Ready");
- }
- else {
- Serial.print("DMP Initialization Failed: ");
- Serial.println(devStatus);
- }
- }
•
- void loop() {
•
- if (!dmpReady) return;
•
- if (mpu.dmpGetCurrentFIFOPacket(fifoBuffer)) {
•
- mpu.dmpGetQuaternion(&q, fifoBuffer);
•
- mpu.dmpGetGravity(&gravity, &q);
•
- mpu.dmpGetYawPitchRoll(ypr, &q, &gravity);
•
- mpu.dmpGetGyro(&gy, fifoBuffer);
•
- | float yaw | = ypr[0] * 180/M_PI;
- float pitch = ypr[1] * 180/M_PI;
- float roll = ypr[2] * 180/M_PI;
•
- Serial.print("Yaw: ");
- Serial.print(yaw);
•
- Serial.print(" Pitch: ");
- Serial.print(pitch);
•
- Serial.print(" Roll: ");
- Serial.print(roll);
•
- Serial.print(" Gyro Y: ");
- Serial.println(gy.y / 131.0);
- }
- }
•
- A.2: NEMA 17 Stepper Motor Driver and Microstepping Calibration Test
- #define stepPin 3
- #define dirPin 4
- void setup() {

- pinMode(stepPin, OUTPUT);
- pinMode(dirPin, OUTPUT);
- }
•
- void loop() {
•
- digitalWrite(dirPin, HIGH);
•
- for(int x = 0; x < 200; x++) {
- digitalWrite(stepPin, HIGH);
- delayMicroseconds(800);
•
- digitalWrite(stepPin, LOW);
- delayMicroseconds(800);
- }
•
- delay(1000);
•
- digitalWrite(dirPin, LOW);
•
- for(int x = 0; x < 200; x++) {
- digitalWrite(stepPin, HIGH);
- delayMicroseconds(800);
•
- digitalWrite(stepPin, LOW);
- delayMicroseconds(800);
- }
•
- delay(1000);
- }

### 13.2 Appendix B: Embedded Control Firmware (C++/Arduino Platform)

- B.1: Integrated Main Architecture for the Core Mechatronic System
- // I2Cdev and MPU6050 must be installed as libraries
- #include "I2Cdev.h"
- #include "MPU6050_6Axis_MotionApps20.h"
- #if I2CDEV_IMPLEMENTATION == I2CDEV_ARDUINO_WIRE
- #include "Wire.h"
- #endif
- MPU6050 mpu;
- // MPU control/status vars
- bool dmpReady = false; // set true if DMP init was successful
- | uint8_t devStatus; | // return status after each device operation (0 =
| success, !0 = error)
- | uint16_t packetSize; | // expected DMP packet size (default is 42 bytes)
- uint8_t fifoBuffer[64]; // FIFO storage buffer
- // orientation/motion vars

- | Quaternion q; | // [w, x, y, z] | quaternion container
- | VectorInt16 gy; | // [x, y, z] | gyro sensor measurements (Angular
| Velocity)
- | VectorFloat gravity; | // [x, y, z] | gravity vector
- | float ypr[3]; | // [yaw, pitch, roll] | yaw/pitch/roll container
- /////////////////////////////////////////////////////////////////////////////////
| //////
- /////////////////////////////////////////////////////////////////////////////////
| ///
- ////////////////////////LQR ////////////////////////////
- const float Fixed_Theta1 = 1.0; //Rad
- //////////(LQR Gain)//////////
- float p_k1[] = {0.074114, -0.173704, -1.929676};
- float p_k2[] = {-0.021690, 0.050877, -0.223459};
- ////////(Lleg & Lw)///////
- float a1 = -0.072848, b1 = 0.205408, c1 = 0.094574;
- float a3 = -0.037861, b3 = 0.088834, c3 = 0.113857;
- //////////variables/////////
- float Lleg = 0;
- | float Lw = 0 ; | // effective Length (pendulum Length)
- float k_pitch, k_pitch_rate;
- ////////States variable from IMU //////////
- float current_pitch, current_gyro_y;
- float target_pitch = 0;
- /////////////////////////////////////////////////////////////////////////////////
| //////////////////
- ////////////////////Stepper ////////////////
- // Left wheel motor
- byte step_L =5;
- byte dir_L =6;
- // Right wheel motor
- byte step_R= 7;
- byte dir_R =8;
•
- long stepDelay = 0;
- unsigned long lastStepTime = 0;
- const int min_delay = 200;
- const int max_delay = 5000;
•
- /////////////////////
- /////////////////////////////////////////////////////////////////////////////////
| //////
- /////////////////////
- void setup() {
- // Arduino Nano uses pins A4 (SDA) and A5 (SCL) automatically
- Wire.begin();
- Wire.setClock(400000); // 400kHz I2C clock
- Serial.begin(115200);
- while (!Serial);

- Serial.println(F("Initializing MPU6050..."));
- mpu.initialize();
- // Verify connection
- Serial.println(mpu.testConnection() ? F("MPU6050 connection successful") : F("MPU6050 connection failed"));
- // Load and configure the DMP
- devStatus = mpu.dmpInitialize();
- // Supply your own gyro offsets here, scaled for min sensitivity
- mpu.setXGyroOffset(220);
- mpu.setYGyroOffset(76);
- mpu.setZGyroOffset(-85);
- mpu.setZAccelOffset(1788);
- if (devStatus == 0) {
- // Calibration
- mpu.CalibrateAccel(6);
- mpu.CalibrateGyro(6);
•
- Serial.println(F("Enabling DMP..."));
- mpu.setDMPEnabled(true);
- dmpReady = true;
•
- packetSize = mpu.dmpGetFIFOPacketSize();
- } else {
- Serial.print(F("DMP Initialization failed (code "));
- Serial.print(devStatus);
- Serial.println(F(")"));
•
- }
- ///////////////Stepper////////////////
- pinMode(step_L, OUTPUT);
- pinMode(dir_L, OUTPUT);
- pinMode(step_R, OUTPUT);
- pinMode(dir_R, OUTPUT);
•
- //////////////////////LQR/////////////////////////
- k_pitch = p_k1[0]*pow(Fixed_Theta1, 2) + p_k1[1]*Fixed_Theta1 + p_k1[2];
- k_pitch_rate = p_k2[0]*pow(Fixed_Theta1, 2) + p_k2[1]*Fixed_Theta1 + p_k2[2];
- Lleg = a1*pow(Fixed_Theta1, 2) + b1*Fixed_Theta1 + c1;
- Lw = a3*pow(Fixed_Theta1, 2) + b3*Fixed_Theta1 + c3;
•
- }
- void loop() {
- if (!dmpReady) return;
- // Read a packet from FIFO
- if (mpu.dmpGetCurrentFIFOPacket(fifoBuffer)) {
- // Get orientation data
- mpu.dmpGetQuaternion(&q, fifoBuffer);
- mpu.dmpGetGravity(&gravity, &q);
- mpu.dmpGetYawPitchRoll(ypr, &q, &gravity);

•
- // Get angular velocity data (Gyro)
- mpu.dmpGetGyro(&gy, fifoBuffer);
•
- // Send data to serial (Yaw, Pitch, Roll, and Gyro X,Y,Z)
- sendReadings(ypr[0], ypr[1], ypr[2], gy.x, gy.y, gy.z);
•
- float torque = LQR_Calculation();
- stepper_control(torque);
- }
- ///////////////////////////////////////////////////////////////////////////////// //////////////////
•
- }
- float LQR_Calculation() {
- current_pitch = ypr[1];
- current_gyro_y = gy.y / 131.0;
- // Error
- float pitch_error = current_pitch - target_pitch;
- float rate_error = current_gyro_y;
- //Torque
- float T_bal = (k_pitch * pitch_error) + (k_pitch_rate * rate_error);
- return T_bal;
- }
•
- void sendReadings(float yaw_rad, float pitch_rad, float roll_rad, int16_t gx, int16_t gy, int16_t gz) {
- // Convert radians to degrees
- float yaw_deg = yaw_rad * 180.0 / M_PI;
- float pitch_deg = pitch_rad * 180.0 / M_PI;
- float roll_deg = roll_rad * 180.0 / M_PI;
- // Printing Angles
- Serial.print("Yaw:"); Serial.print(yaw_deg);
- Serial.print("\tPitch:"); Serial.print(pitch_deg);
- Serial.print("\tRoll:"); Serial.print(roll_deg);
- // Printing Angular Velocities (Raw values from Gyro)
- Serial.print("\t| GX:"); Serial.print(gx);
- Serial.print("\tGY:"); Serial.print(gy);
- Serial.print("\tGZ:"); Serial.println(gz);
- }
•
- void stepper_control(float torque) {
•
- if (torque > 0) {
- digitalWrite(dir_L, HIGH);
- digitalWrite(dir_R, LOW);
- } else {
- digitalWrite(dir_L, LOW);
- digitalWrite(dir_R, HIGH);

- }
- float abs_torque = abs(torque);
•
- if (abs_torque < 0.05) {
- stepDelay = 0;
- } else {
•
- stepDelay = 80000 / abs_torque;
- if (stepDelay < min_delay) stepDelay = min_delay;
- if (stepDelay > max_delay) stepDelay = max_delay;
- }
- run_motors();
- }
•
- void run_motors() {
- if (stepDelay == 0) return;
•
- if (micros() - lastStepTime >= stepDelay) {
- lastStepTime = micros();
•
- digitalWrite(step_L, HIGH);
- digitalWrite(step_R, HIGH);
- delayMicroseconds(10);
- digitalWrite(step_L, LOW);
- digitalWrite(step_R, LOW);
- Serial.println("motor run");
- }
- }

### 13.3 Appendix C: Dynamic LQR State-Space Controller Implementations

- C.1: 4-State Longitudinal Motion and Pitch Balance Control Script (x-Motion)

% --- Physical Constants ---

m = 0.9 ; % wheel mass
M = 2.5 ; % Body Mass
r = 0.05 ; % wheel radius
L = 0.15 ; % length to CoM Jz = 0.03 ; % body inertia
Iw = 0.000045 ; % wheel inertia g = 9.81; % gravity

Ew = M + 2*m + (2*Iw/ (r^2)) ;
Ep = (Jz + M*(L^2)) ;
denometer = Ew * Ep - ( (M^2)*(L^2)) ;

A21 = (Ew*M*g*L )/denometer ;
B2 = -1* (Ew + M*L/r) /denometer; A41 = ( -1* (M^2)*g*(L^2) )/denometer ; B4 = ( (Ep/r) + M*L )/denometer ;

A_Mat = [ 0 | 1 | 0 | 0
A21 | 0 | 0 | 0
0 | 0 | 0 | 1
A41 | 0 | 0 | 0 ] ;

B_Mat = [ 0
B2
0
B4 ] ;
C_Mat = [ 1 0 | 0 | 0
0 1 | 0 | 0
0 0 | 1 | 0
0 0 | 0 | 1 ] ;

Q = diag([200, 0, 500, 0]); R = 400 ;

K = lqr(A_Mat, B_Mat, Q, R) ;

- C.2: 6-State Spatial Trajectory Tracking and Yaw Steering Control Script (X-Y-Motion)

% --- Physical Constants ---

% XY motion with balancing
% X state vector = [ Θ Θ_dot x x_dot δ δ_dot ] % J cost function = 0∫∞ (xTQx+uTRu) dt

m = 0.9 ; % wheel mass
M = 2.5 ; % Body Mass
r = 0.05 ; % wheel radius
L = 0.15 ; % length to CoM
Jz = 0.03 ; % body inertia about the yaw axis (horizontal) Jy = 0.005; % Moment of inertia about the yaw axis (vertical) Iw = 0.000045 ; % wheel inertia
g = 9.81; | % gravity
D = 0.15; | % track width
Ew = M + 2*m + (2*Iw/ (r^2)) | ;
Ep = (Jz + M*(L^2)) ;
denometer = Ew * Ep - ( (M^2)*(L^2)) ;

A21 = (Ew*M*g*L )/denometer ;
B2 = -1* (Ew + M*L/r) /denometer;
A41 = ( -1* (M^2)*g*(L^2) )/denometer ;
B4 = ( (Ep/r) + M*L )/denometer ;
B6 = 1 /(r*(m*D + (Iw*D)/(r^2) + 2*Jy/D)) ;
A_Mat = [ 0 | 1 | 0 | 0 | 0 | 0
A21 | 0 | 0 | 0 | 0 | 0
0 | 0 | 0 | 1 | 0 | 0
A41 | 0 | 0 | 0 | 0 | 0
0 | 0 | 0 | 0 | 0 | 1
0 | 0 | 0 | 0 | 0 | 0 ] ;

B_Mat = [ 0 | 0
B2 | 0
0 | 0
B4 | 0
0 | 0
0 | B6] ;
C_Mat = [ 1 0 | 0 | 0 | 0 0
0 1 | 0 | 0 | 0 0
0 0 | 1 | 0 | 0 0
0 0 | 0 | 1 | 0 0
0 0 | 0 | 0 | 1 0
0 0 | 0 | 0 | 0 1 ] ;
D_Mat = [ 0 | 0
0 | 0
0 | 0
0 | 0
0 | 0
0 | 0] ;

Q = diag([200, 0, 500, 0 , 300 , 0 ]); R = diag([400 , 300 ]) ;

K = lqr(A_Mat, B_Mat, Q, R) ;

### 13.4 Appendix D: High-Level Simulation and Control Initialization Scripts

- D.1: Simulink LQR State-Space Block Initialization and Workspace Configuration Script

% --- Physical Constants ---

m = 0.1 ; % wheel mass
M = 0.9 ; % Body Mass
r = 0.05 ; % wheel radius
L = 0.15 ; % length to CoM Jz = 0.03 ; % body inertia
Iw = 0.000045 ; % wheel inertia g = 9.81; % gravity

Ew = M + 2*m + (2*Iw/ (r^2)) ;
Ep = (Jz + M*(L^2)) ;
denometer = Ew * Ep - ( (M^2)*(L^2)) ;

A21 = (Ew*M*g*L )/denometer ;
B2 = -1* (Ew + M*L/r) /denometer; A41 = ( -1* (M^2)*g*(L^2) )/denometer ; B4 = ( (Ep/r) + M*L )/denometer ;
A_Mat = [ 0 | 1 | 0 | 0
A21 | 0 | 0 | 0
0 | 0 | 0 | 1
A41 | 0 | 0 | 0 ] ;

B_Mat = [ 0
B2

B4 ] ;

C_Mat = [ 1 0 | 0 | 0
0 1 | 0 | 0
0 0 | 1 | 0
0 0 | 0 | 1 ] ;

Q = diag([200, 0, 500, 0]); R = 400 ;

K = lqr(A_Mat, B_Mat, Q, R) ;

- D.2: Inverse Kinematics Function Block

function [theta1_cmd, theta6_cmd] = fcn(l_desired, l1, l2, l3, l4, l23)
% Compute inverse mapping configuration for upper actuator input
arg1 = (l_desired^2 + l2^2 - l1^2) / (2 * l_desired * l2);
arg1 = max(min(arg1, 1), -1); % Bound argument to prevent imaginary roots theta1_cmd = asin(arg1);

% Resolve intermediate auxiliary vector distance
l5 = sqrt(l2^2 + l4^2 - 2*l2*l4*cos(theta1_cmd + pi/4));

% Evaluate downstream inter-link angle transformations theta2 = asin((l4 * sin(theta1_cmd + pi/4)) / l5);

arg3 = (l23^2 + l5^2 - l3^2) / (2 * l23 * l5);
arg3 = max(min(arg3, 1), -1);
theta3 = acos(arg3);

theta4 = pi - theta1_cmd - theta2 - theta3;

% Formulate lower link companion positioning command arg6 = (l5 * sin(theta3)) / l3;
arg6 = max(min(arg6, 1), -1);
theta6_cmd = asin(arg6) - theta4;
end
D.3:: Closed-Form Forward Leg Kinematics and COM Profiler (Leg_Kinematics.m)

function [lleg, L0, lw] = fcn(theta1, l1, l2, l3, l4, l23, m1, m2, m3, m23)
% Reconstruct dynamic loop-closure parameters from instantaneous state
l5 = sqrt(l2^2 + l4^2 - 2 * l2 * l4 * cos(theta1 + pi/4));

arg_asin = (l4 * sin(theta1 + pi/4)) / l5;
arg_asin = max(min(arg_asin, 1), -1);
theta2 = asin(arg_asin);

arg_acos = (l23^2 + l5^2 - l3^2) / (2 * l23 * l5); arg_acos = max(min(arg_acos, 1), -1);
theta3 = acos(arg_acos);

theta4 = pi - theta1 - theta2 - theta3;

theta5 = pi - theta4;

arg_asin_theta6 = (l5 * sin(theta3)) / l3; arg_asin_theta6 = max(min(arg_asin_theta6, 1), -1); theta6 = asin(arg_asin_theta6) - theta4;

% Calculate exact output linear height profile
lleg = l2 * sin(theta1) + l1 * sin(theta4);

% Determine discrete spatial mass center coordinates for individual components xc2 = (l2 * sin(theta1)) / 2;
xc1 = l2 * sin(theta1) + (l1 * sin(theta5)) / 2;
xc3 = -l4 * sin(pi/4) + (l3 * sin(theta6)) / 2;
xc23 = l2 * sin(theta1) - (l23 * sin(theta4)) / 2;

% Mass-weighted composite center of gravity tracking calculation
L0 = (m1*xc1 + m2*xc2 + m3*xc3 + m23*xc23) / (m1 + m2 + m3 + m23);

% Global vertical system center of mass displacement offset
lw = lleg - L0;
end
D.4: Virtual Model Control (VMC) Jacobian Mapping Function (Virtual_Model_Control.m)

function [T_link2, l5] = fcn(F0, theta1, l1, l2, l3, l4, l23)
% Compute instantaneous linkage frame spatial transformation vectors
l5 = sqrt(l2^2 + l4^2 - 2*l2*l4*cos(theta1 + pi/4));

alpha_val = asin((l4 * sin(theta1 + pi/4)) / l5);

cos_beta_arg = (l23^2 + l5^2 - l3^2) / (2 * l23 * l5);
cos_beta_arg = max(min(cos_beta_arg, 1), -1);
beta_val = acos(cos_beta_arg);

% Formulate scalar component configuration entry for the System Jacobian J1 = l2 * cos(theta1) + l1 * cos(theta1 + alpha_val + beta_val);

% Translate operational structural load to joint-space motor output torque T_link2 = F0 * J1;
end
D.5: Compliance Actuator Compliance and Deflection Mapping (Servo_Actuator.m)

function theta_final = fcn(theta_cmd, torque_vmc, joint_stiffness)
% Compute physical angular link displacement caused by loading profile
delta_theta = torque_vmc / joint_stiffness;

% Superimpose elastic structural deflection onto nominal angle positioning command theta_final = theta_cmd + delta_theta;
end

### 13.5 Appendix E: Offline MATLAB Numerical Fitting and Matrix Scheduling Scripts

- E.1: Least-Squares Kinematic Geometry Fitting (llegandlw Profile Approximation vs. θ1)

% ========================================================================= % TWSB Robot: Kinematic Fitting & Validation Script
% Added: Comparison plots for Leg Length and CG Offset accuracy
% ========================================================================= clear; clc; close all;

% --- 1. Physical Constants ---
l1 = 0.5; l2 = 0.15; l3 = 0.15; l4 = 0.1; l23 = 0.1;
m1 = 0.2; m2 = 0.3; m3 = 0.1; m23 = 0.8;
m_legs = m1 + m2 + m3 + m23;

% --- 2. Data Generation Loop ---
theta1_range = linspace(0.5, 1.25, 100); Lleg_data = zeros(size(theta1_range)); LW_data = zeros(size(theta1_range));

for i = 1:length(theta1_range)
theta1 = theta1_range(i);

% Kinematic equations
l5 = sqrt(l2^2 + l4^2 - 2 * l2 * l4 * cos(theta1 + pi/4));
theta2 = asin(max(-1, min(1, (l4 * sin(theta1 + pi/4)) / l5))); theta3 = acos(max(-1, min(1, (l23^2 + l5^2 - l3^2) / (2 * l23 * l5)))); theta4 = pi - theta1 - theta2 - theta3;
theta5 = pi - theta4;
theta6 = asin(max(-1, min(1, (l5 * sin(theta3)) / l3))) - theta4;

lleg = l2 * sin(theta1) + l1 * sin(theta4);

xc2 = (l2 * sin(theta1)) / 2;
xc1 = l2 * sin(theta1) + (l1 * sin(theta5)) / 2; xc3 = -l4 * sin(pi/4) + (l3 * sin(theta6)) / 2; xc23 = l2 * sin(theta1) - (l23 * sin(theta4)) / 2;

L0 = (m1*xc1 + m2*xc2 + m3*xc3 + m23*xc23) / m_legs; lw = lleg - L0;

Lleg_data(i) = lleg;
LW_data(i) = lw;
end

% --- 3. Perform Quadratic Fittings ---p_theta1_lleg = polyfit(theta1_range, Lleg_data, 2); p_theta1_lw = polyfit(theta1_range, LW_data, 2);

% Calculate fitted values for validation
Lleg_fit = polyval(p_theta1_lleg, theta1_range);
Lw_fit = polyval(p_theta1_lw, theta1_range);

% --- 4. Original Visualization (Fitting Curves) ---
figure('Name', 'Fitting Analysis', 'Color', 'w', 'Position', [50, 400, 1200, 400]); subplot(1, 3, 1);
plot(theta1_range, Lleg_data, 'ro', 'MarkerSize', 3); hold on;
plot(theta1_range, Lleg_fit, 'b-', 'LineWidth', 2);
grid on; title('\theta_1 \rightarrow l_{leg}'); ylabel('m');

subplot(1, 3, 2);
plot(Lleg_data, LW_data, 'go', 'MarkerSize', 3); hold on; [lleg_sorted, idx] = sort(Lleg_data);
p_lleg_lw = polyfit(Lleg_data, LW_data, 2);

plot(lleg_sorted, polyval(p_lleg_lw, lleg_sorted), 'b-', 'LineWidth', 2); grid on; title('l_{leg} \rightarrow l_w');

subplot(1, 3, 3);
plot(theta1_range, LW_data, 'mo', 'MarkerSize', 3); hold on; plot(theta1_range, Lw_fit, 'b-', 'LineWidth', 2);
grid on; title('\theta_1 \rightarrow l_w');

% --- 5. Validation Window (Real vs Fit Comparison) ---
figure('Name', 'Accuracy Validation', 'Color', 'w', 'Position', [50, 50, 1000, 500]);

% Subplot A: Leg Length Comparison
subplot(2, 2, 1);
plot(theta1_range, Lleg_data, 'k', 'LineWidth', 2); hold on;
plot(theta1_range, Lleg_fit, 'r--', 'LineWidth', 1.5);
grid on; legend('Real (Eq)', 'Fitted');
ylabel('L_{leg} (m)'); title('Leg Length: Real vs Quadratic Fit');

% Subplot B: Leg Length Error
subplot(2, 2, 3);
plot(theta1_range, abs(Lleg_data - Lleg_fit), 'd-');
grid on; ylabel('Abs Error (m)'); xlabel('Servo Angle (rad)'); title('L_{leg} Fitting Residuals');

% Subplot C: Lw Comparison
subplot(2, 2, 2);
plot(theta1_range, LW_data, 'k', 'LineWidth', 2); hold on; plot(theta1_range, Lw_fit, 'm--', 'LineWidth', 1.5);
grid on; legend('Real (Eq)', 'Fitted');
ylabel('L_w (m)'); title('CG Offset (Lw): Real vs Quadratic Fit');

% Subplot D: Lw Error
subplot(2, 2, 4);
plot(theta1_range, abs(LW_data - Lw_fit), 'd-', 'Color', [0.5 0 0.5]); grid on; ylabel('Abs Error (m)'); xlabel('Servo Angle (rad)'); title('L_w Fitting Residuals');

% --- 6. Output Coefficients ---
fprintf('\n--- COPY THESE COEFFICIENTS TO YOUR ARDUINO CODE ---\n'); fprintf('// Fitting: theta1 -> Lleg\n');
fprintf('float a1 = %f; float b1 = %f; float c1 = %f;\n', p_theta1_lleg); fprintf('\n// Fitting: Lleg -> Lw\n');
fprintf('float a2 = %f; float b2 = %f; float c2 = %f;\n', p_lleg_lw); fprintf('\n// Fitting: theta1 -> Lw\n');
fprintf('float a3 = %f; float b3 = %f; float c3 = %f;\n', p_theta1_lw);
- E.2: Optimal Feedback Gain Curve-Fitting and Polynomial lookup Generation (KMatrix Allocation vs. θ_1)

% =========================================================================
% LQR Validation Script: Exact Gains vs. Polynomial Fitting
% =========================================================================

clear; clc; close all;

% --- 1. System Constants ---
theta1_range = linspace(0.5, 2.5, 50);
m_w = 0.2; mb = 0.9; ml = 0.4; mp = mb + 2*ml; r = 0.05; g = 9.81; D = 0.15; lb = 0.12;

Jz_body = 0.033; Iw = 0.00025;
Jy_base = 0.008;

% Geometry fittings (Inputs)
a_lw = -0.010700; b_lw = 0.038542; c_lw = 0.345832; a_lleg = -0.087522; b_lleg = 0.263838; c_lleg = 0.307096;

% LQR Weights
Q = diag([200, 10, 500, 10, 300, 10]);
R = diag([400, 300]);

% --- 2. Step-by-Step Mathematical Calculation (Exact Data) ---
K_exact = zeros(length(theta1_range), 6); % To store 6 gains for each angle

for i = 1:length(theta1_range)
t1 = theta1_range(i);

% Update physics exactly for this step lw = a_lw*t1^2 + b_lw*t1 + c_lw;
lleg = a_lleg*t1^2 + b_lleg*t1 + c_lleg;
L = (lb*mb + lw*(2*ml)) / mp;
Ip = Jz_body + mb*(lb - L)^2 + (2*ml)*(L - lw)^2; Jy = Jy_base + (2 * ml * (D/2)^2) * (lleg / 0.45);

% Matrix construction
Ew = mp + 2*m_w + (2*Iw / (r^2));
Ep = Ip;
denom = Ew * Ep - (mp^2 * L^2);

A21 = (Ew * mp * g * L) / denom;
B2 = -1 * (Ew + mp * L / r) / denom;
A41 = (-1 * mp^2 * g * L^2) / denom;
B4 = (Ep / r + mp * L) / denom;
B6 = 1 / (r * (m_w * D + (Iw * D) / (r^2) + 2 * Jy / D));

A = [0 1 0 0 0 0; A21 0 0 0 0 0; 0 0 0 1 0 0; A41 0 0 0 0 0; 0 0 0 0 0 1; 0 0 0 0 0 0];
B = [0 0; B2 0; 0 0; B4 0; 0 0; 0 B6];

% The Mathematical Truth
K_temp = lqr(A, B, Q, R);
K_exact(i, :) = [K_temp(1,1:4), K_temp(2,5:6)]; % Store relevant gains
end

% --- 3. Create Polynomial Fittings ---
titles = {'k1 (Pitch)', 'k2 (Pitch Rate)', 'k3 (Position)', 'k4 (Velocity)', 'k5 (Yaw)', 'k6 (Yaw Rate)'};
p_coeffs = cell(1,6);

figure('Color', 'w', 'Name', 'LQR Fitting Validation');

for j = 1:6
% Fit the polynomial to the exact data
p_coeffs{j} = polyfit(theta1_range, K_exact(:,j), 2);

% Generate fitted line for plotting
K_fit = polyval(p_coeffs{j}, theta1_range);

% Plotting
subplot(2, 3, j);

plot(theta1_range, K_exact(:,j), 'ro', 'MarkerSize', 4, 'DisplayName', 'Math (Exact)'); hold on;
plot(theta1_range, K_fit, 'b-', 'LineWidth', 2, 'DisplayName', 'Fitting (Arduino)'); grid on; title(titles{j});
xlabel('\theta_1 (rad)'); ylabel('Gain Value');
if j == 1, legend('Location', 'best'); end
end

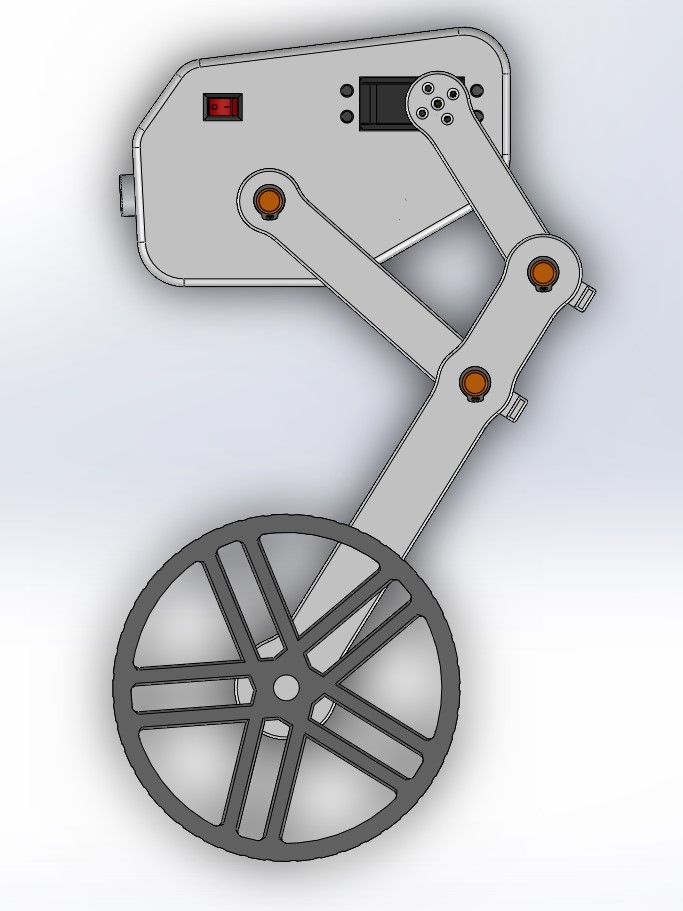
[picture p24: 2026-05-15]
hardware/Version - 2/Side view.jpg

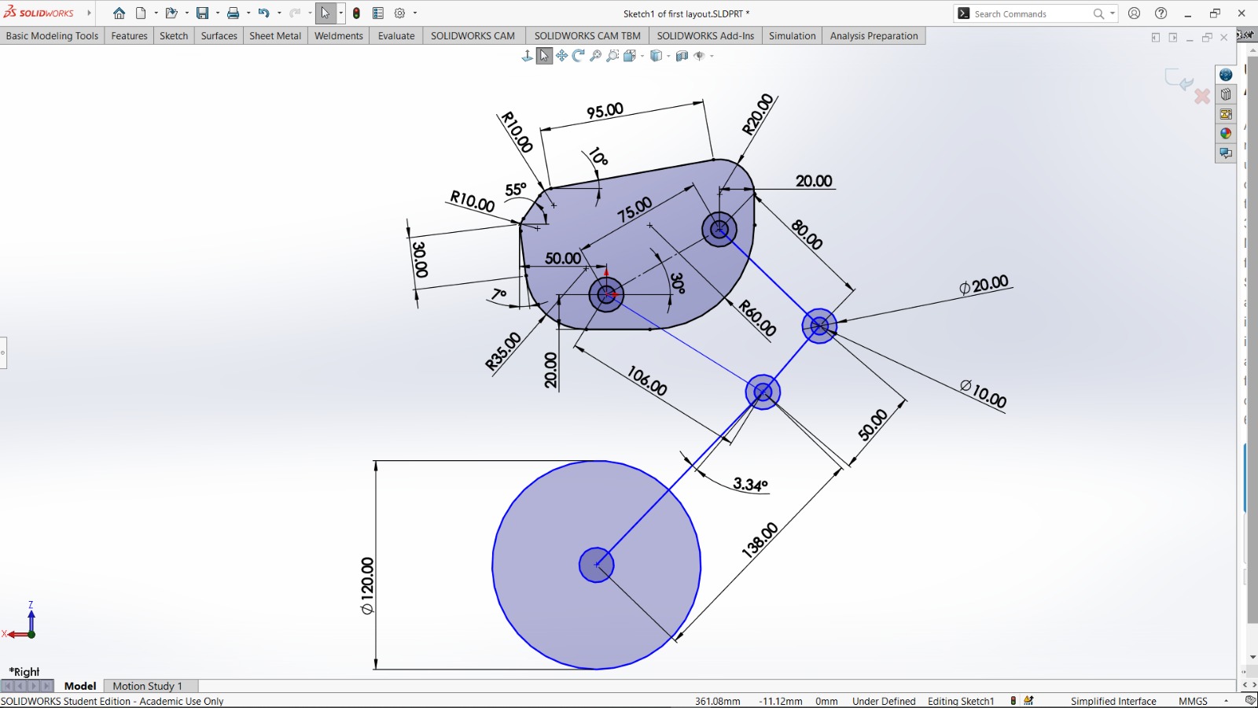
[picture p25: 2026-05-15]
hardware/Version - 1/first layout.jpeg

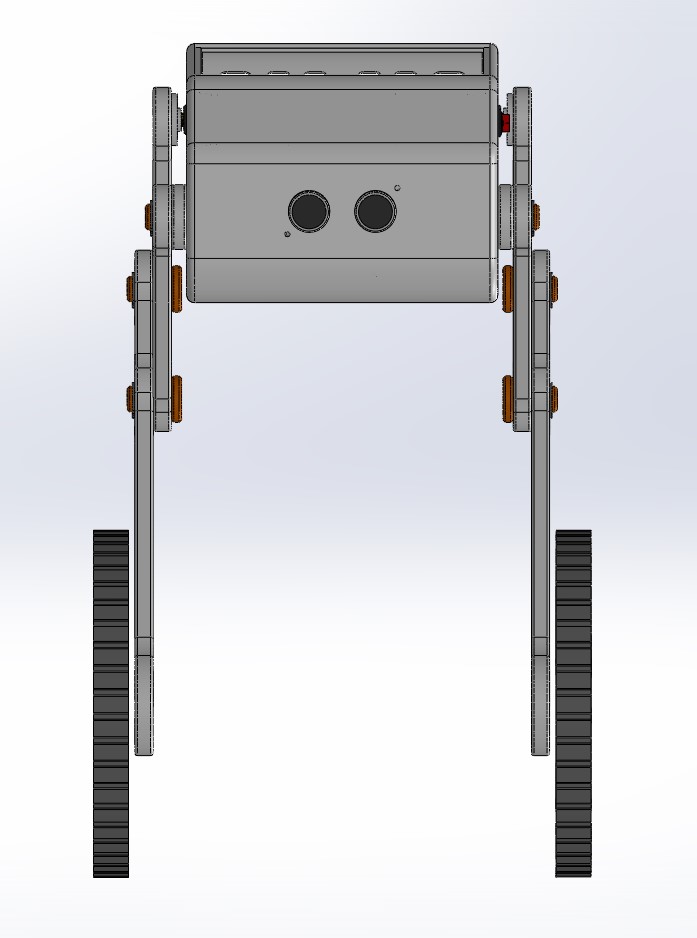
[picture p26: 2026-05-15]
hardware/Version - 2/Elevation.jpg

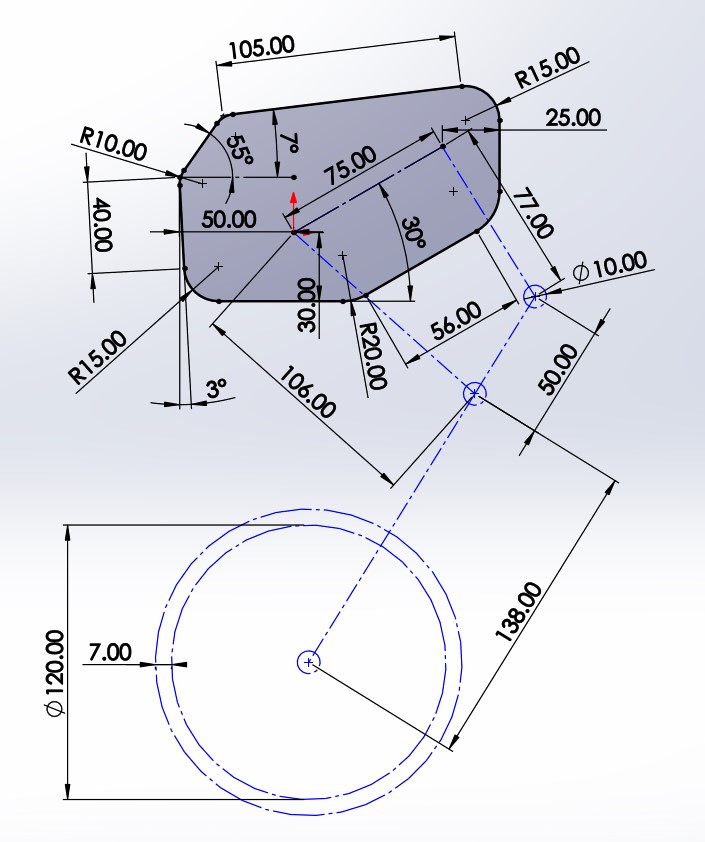
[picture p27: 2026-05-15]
hardware/Version - 2/Second Layout.jpg

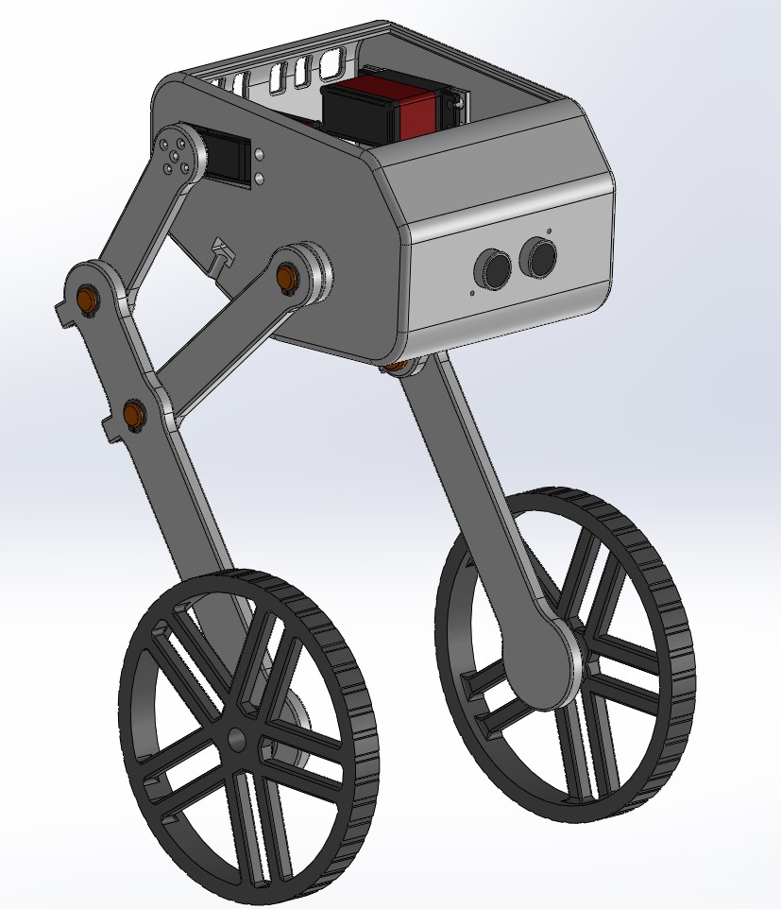
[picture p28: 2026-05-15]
hardware/Version - 2/Isometric.jpg

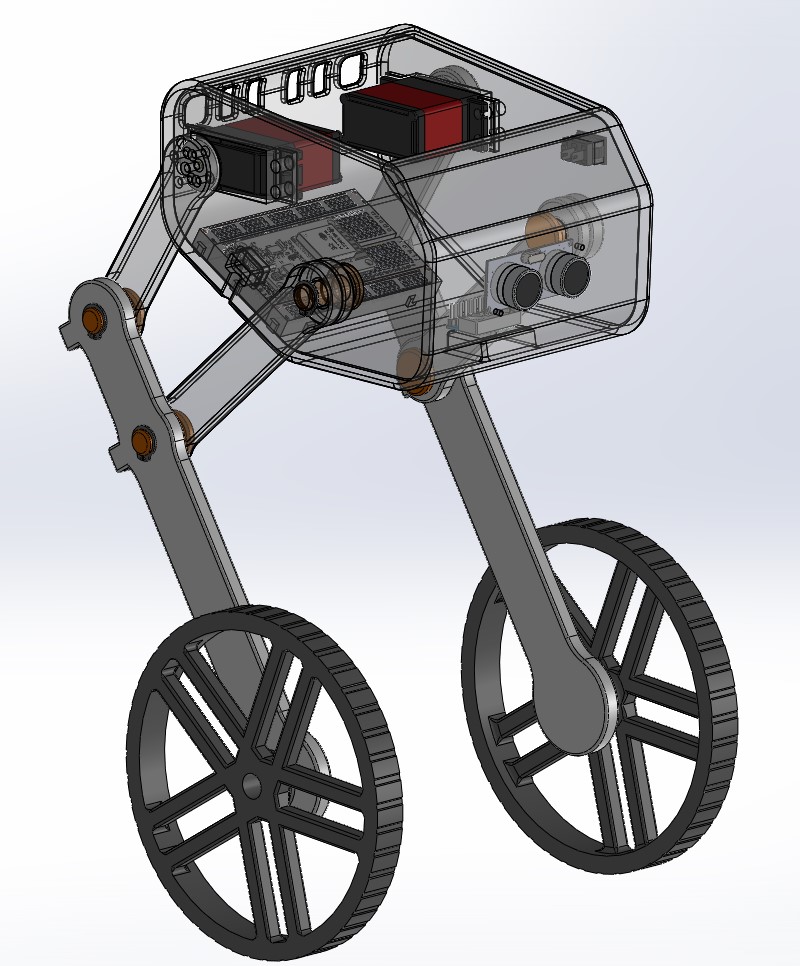
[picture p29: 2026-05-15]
hardware/Version - 2/Isometric transparent.jpg

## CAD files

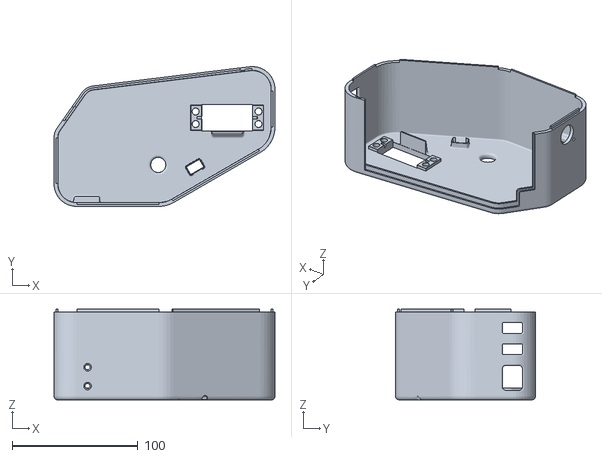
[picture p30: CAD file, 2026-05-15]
hardware/Solidworks CAD Model/3D printed/HEAD Right side.STL
176.0 x 111.4 x 72.3

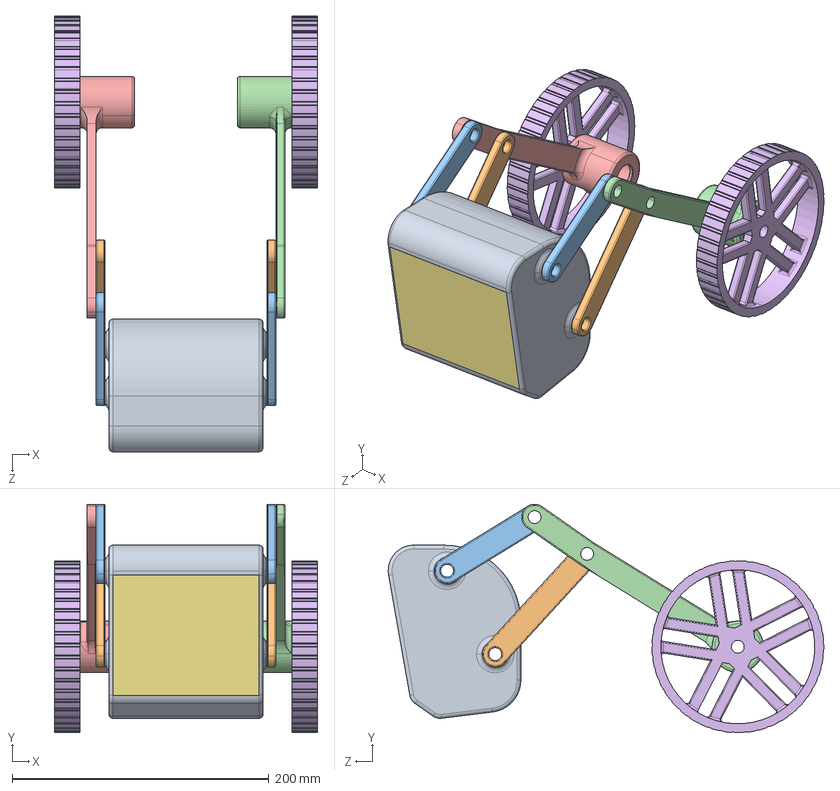
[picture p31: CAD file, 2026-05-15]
hardware/Version - 1/Wheel-Legged Robot.STEP
205.0 x 178.1 x 339.5 mm
Head
Link 1 x 2
Link 2 x 2
Link 3
Link 3- Right
wheel x 2
top cover

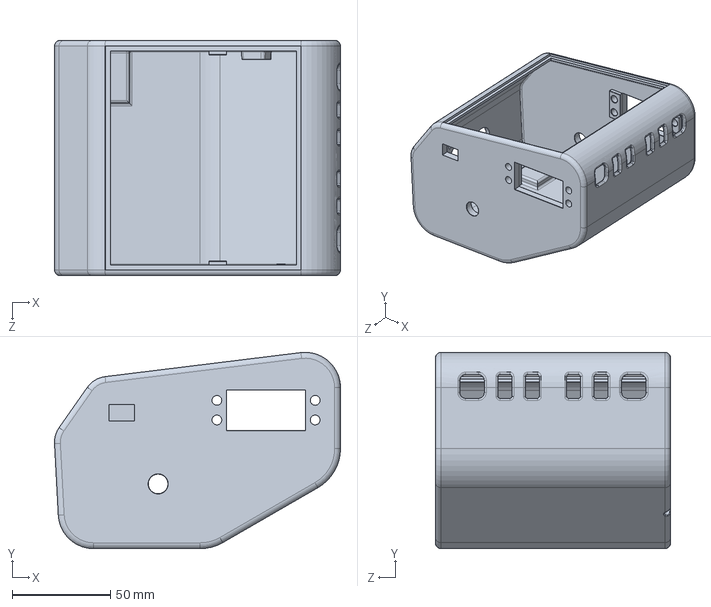
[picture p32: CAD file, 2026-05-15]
hardware/Version - 2/HEAD.SLDPRT
145.8 x 100.1 x 120.0 mm

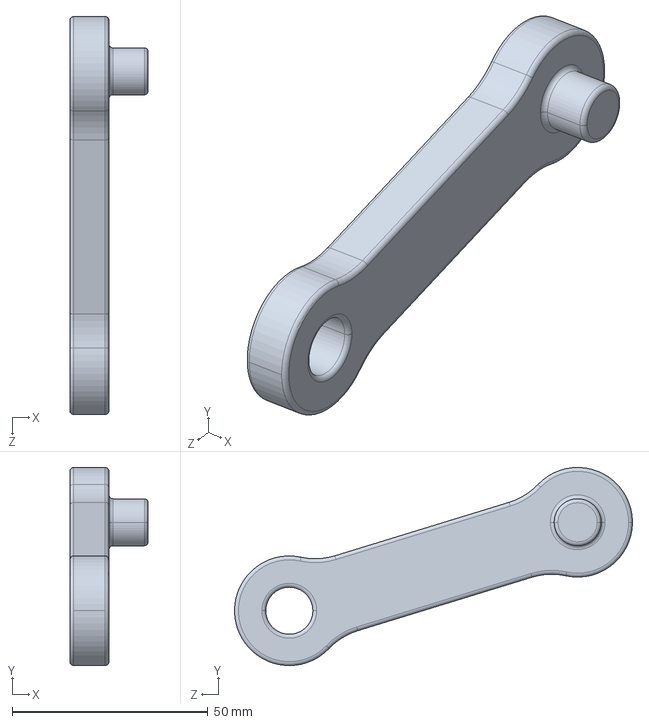
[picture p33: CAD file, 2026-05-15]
simulation/Control/Simscape Model (Environment without control)/Link (Servo)_Default_sldprt.STEP
20.0 x 50.6 x 101.6 mm

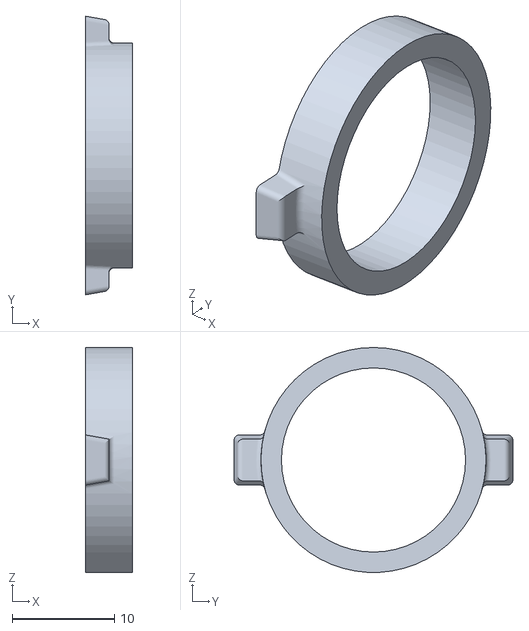
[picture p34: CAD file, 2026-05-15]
hardware/Solidworks CAD Model/3D printed/Bearing Cap.STL
4.60 x 27.2 x 22.0

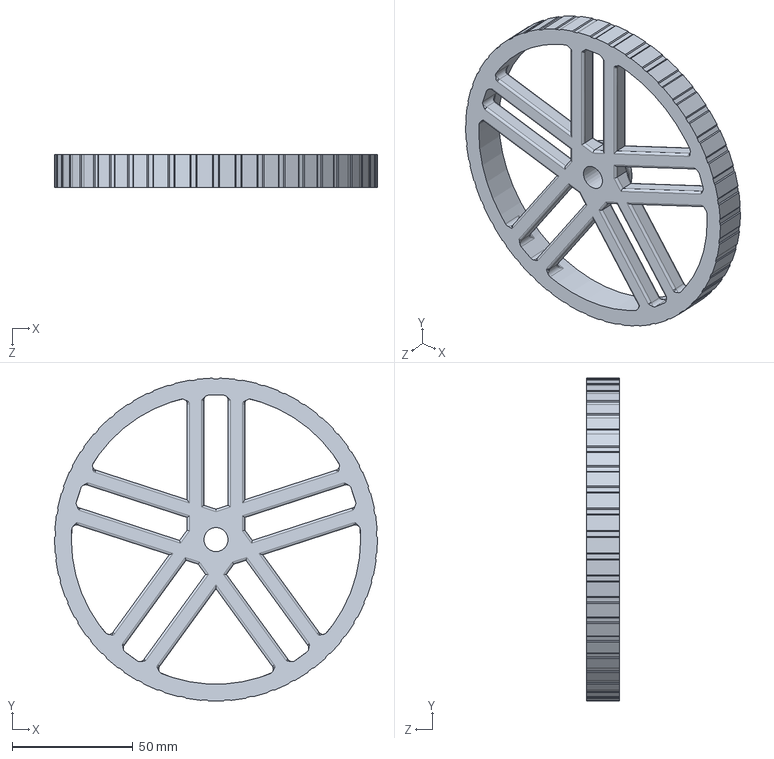
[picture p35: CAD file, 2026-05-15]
hardware/Version - 2/Version2 - 2023/wheel.SLDPRT
134.0 x 133.9 x 13.5 mm

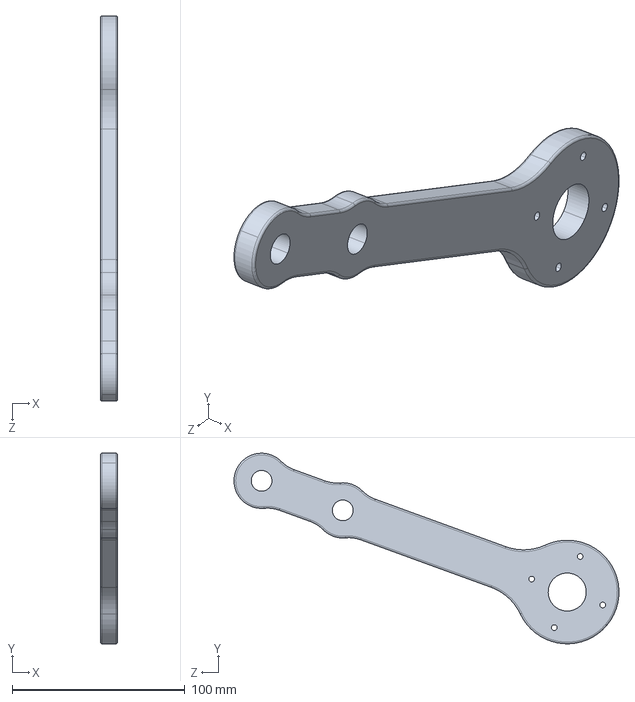
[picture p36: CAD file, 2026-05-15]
simulation/Control/Simscape Model (Environment without control)/Link (Stepper) Right_Default_sldprt.STEP
10.0 x 110.4 x 222.9 mm

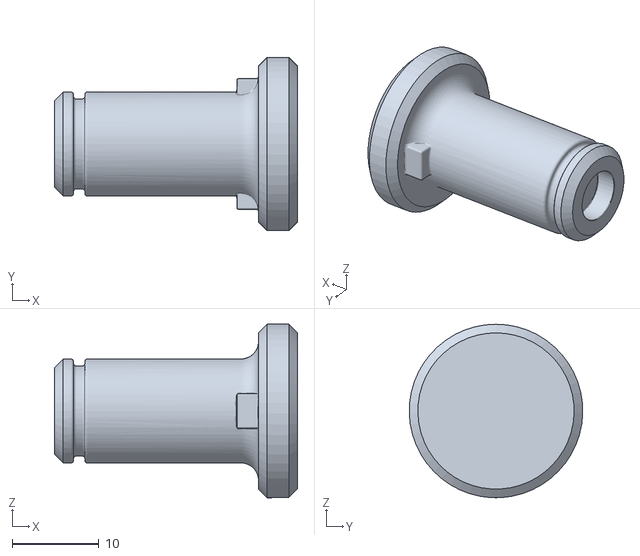
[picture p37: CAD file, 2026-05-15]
hardware/Solidworks CAD Model/3D printed/Pin (Encoder).STL
28.0 x 20.0 x 20.0

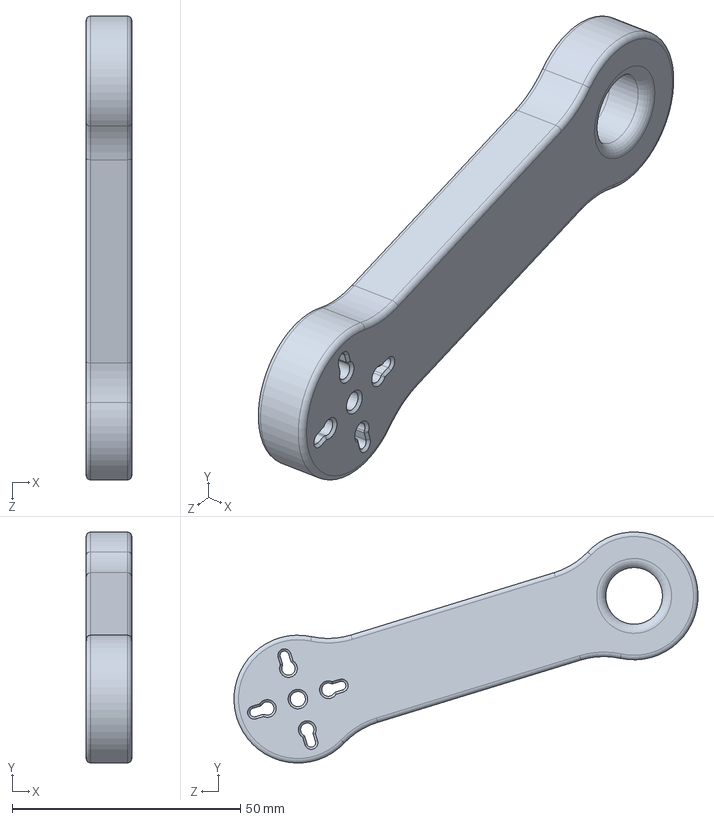
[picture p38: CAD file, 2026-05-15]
hardware/Solidworks CAD Model/Link (Servo).SLDPRT
10.0 x 50.6 x 101.6 mm

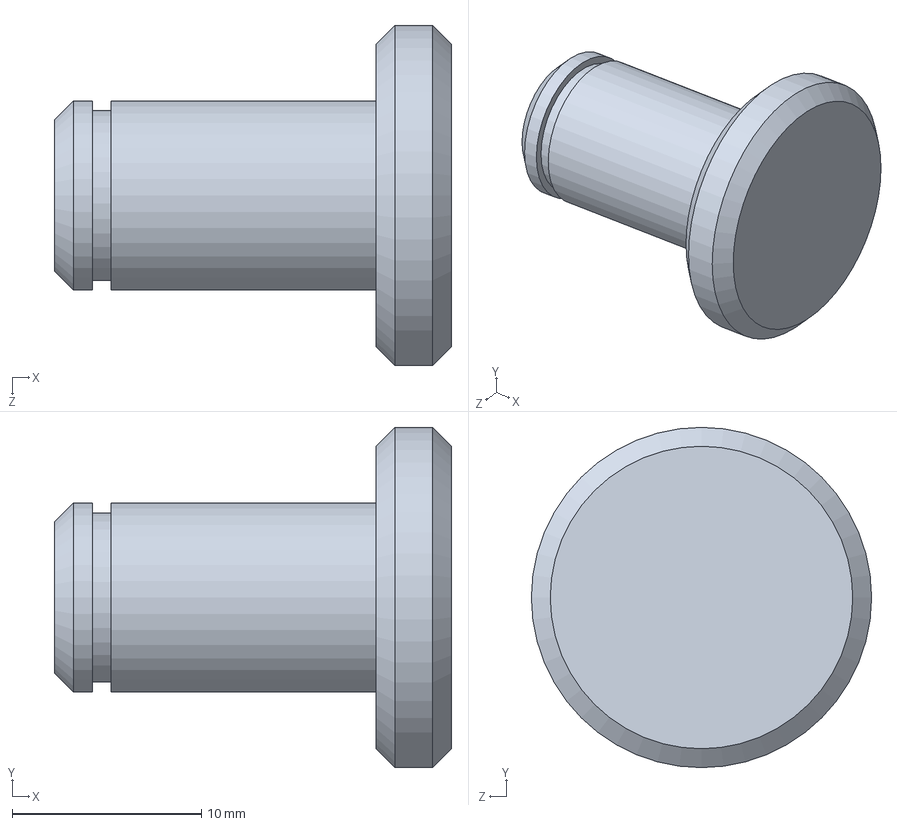
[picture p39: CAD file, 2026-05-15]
hardware/Version - 2/Version2 - 2023/Pin (Links).SLDPRT
21.0 x 18.0 x 18.0 mm

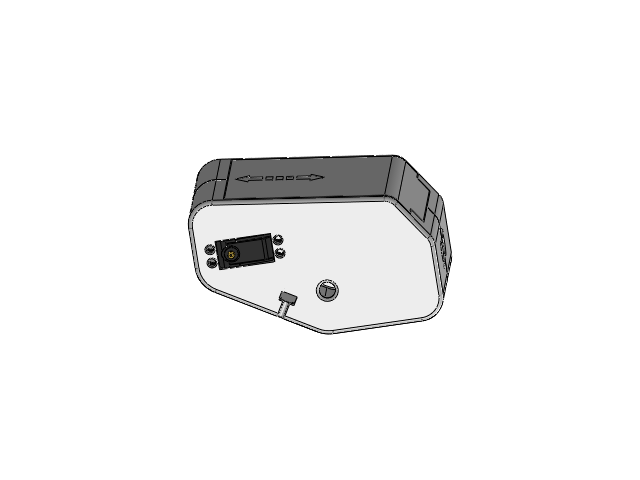
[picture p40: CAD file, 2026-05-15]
hardware/Solidworks CAD Model/HEAD_SubAssem.SLDASM
HEAD Left Side
HEAD Right side
Head Cover
LewanSoul LD-20M Servo 20kg x 2
Ultrasonic_sensor
MPU6050_Sensor

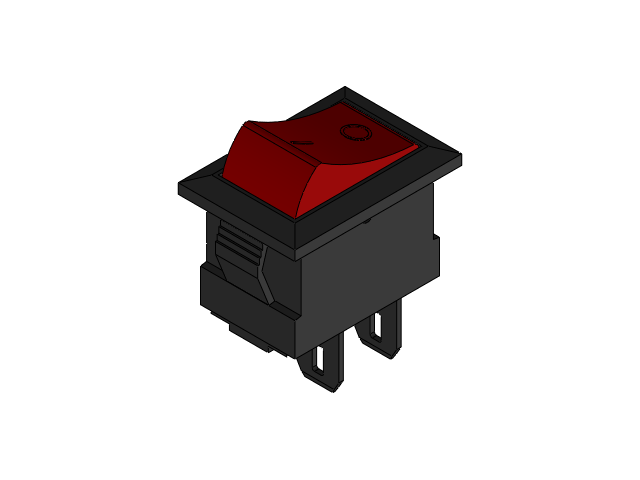
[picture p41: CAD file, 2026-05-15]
hardware/Version - 2/Version2 - 2023/small_MA_switch_b.SLDASM
pin001.step_2.step x 2
Corps001.step_2.step
bouton001.step_2.step

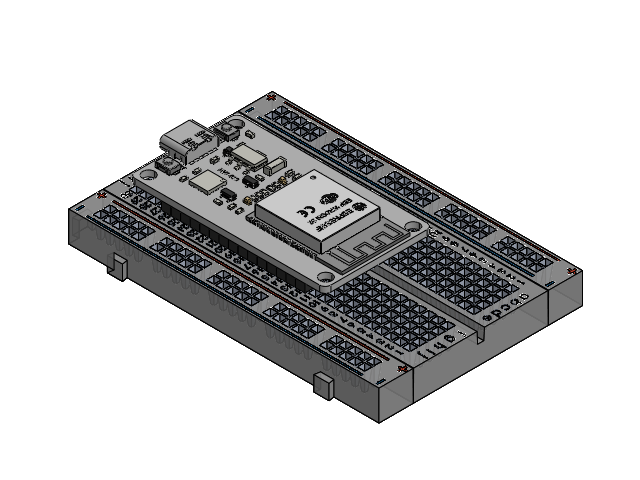
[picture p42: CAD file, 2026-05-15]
hardware/Version - 2/Version2 - 2023/ESP_BreadBoard_SubAssem.SLDASM
BreadBoard
esp32

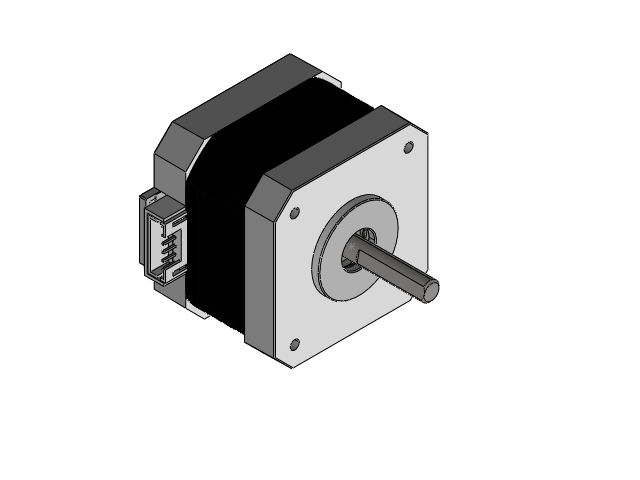
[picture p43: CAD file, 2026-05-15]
hardware/Solidworks CAD Model/Nema 17 Stepper Motor.SLDASM
Nema 17 Top Cap.stp
BS 3469 - 02 - 5 x 16 x 5.stp x 2
Nema 17 Plastic Spacer 2.stp
Nema 17 Plastic Spacer 1.stp
Nema 17 shaft.stp
ANSI B27.7 - 5, E.stp
Nema 17 Base Cap.stp
Nema 17 Central Spacer.stp
Nema 17 Stator Face.stp
Nema 17 plastic.stp
S6B-PH-K-S.stp
EN ISO 7045 - M3 x 25(1).stp x 4
Nema 17 plastic protector.stp
Nema 17 PCB.stp
Nema 17 Sprung Washer.stp

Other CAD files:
hardware/Solidworks CAD Model/small_MA_switch_b.SLDASM
hardware/Version - 2/Version2 - 2023/MPU6050_Assembly.SLDASM
hardware/Solidworks CAD Model/HEAD Right side.SLDPRT
hardware/Solidworks CAD Model/3D printed/Bearing Lock.STL
hardware/Solidworks CAD Model/3D printed/HEAD Left Side.STL
hardware/Solidworks CAD Model/3D printed/Head Cover.STL
hardware/Solidworks CAD Model/3D printed/Link (Servo).STL
hardware/Solidworks CAD Model/3D printed/Link (Stepper) Left.STL
hardware/Solidworks CAD Model/3D printed/Link (Stepper) Right.STL
hardware/Solidworks CAD Model/3D printed/Link (Support).STL
hardware/Solidworks CAD Model/3D printed/Pin (Head)- two times print.STL
hardware/Solidworks CAD Model/3D printed/Pin (Links).STL
hardware/Solidworks CAD Model/3D printed/wheel.STL
hardware/Solidworks CAD Model/Bearing Cap.SLDPRT
hardware/Solidworks CAD Model/Bearing Lock.SLDPRT
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

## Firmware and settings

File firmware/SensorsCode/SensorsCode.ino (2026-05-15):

#include "I2Cdev.h"                      //I2C
#include <Wire.h>                        //I2C
#include "MPU6050_6Axis_MotionApps20.h"  //IMU
#include "AS5600.h"                      //Encoder
#include <HCSR04.h>                      //ultrasonic
#define OUTPUT_READABLE_YAWPITCHROLL     //IMU
#define M_PI 3.14159265358979323846      // pi defination
#define AS5600_RAW_TO_RADIANS (2.0 * M_PI / 4096.0)  // get angle in Radian

volatile bool MPUInterrupt = false;     // Indicates whether MPU6050 interrupt pin has gone high
void DMPDataReady() {
  MPUInterrupt = true;}

//defination 
MPU6050 mpu;   //IMU
AS5600L as5600;          //Encoder
int const INTERRUPT_PIN = 2;  // Define the interruption #0 pin

const byte triggerPin = 5;  // ultrasonic
const byte echoPin = 18;     // ultrasonic
const float safeDistance = 20 ; // ultrasonic

// kinematics constants
const float L1 = 0.138 ;
const float L2 = 0.106 ; 
const float L3 = 0.077 ;
const float L4 = 0.075 ;
const float L23 = 0.050;
const float m1 = 0.025 ;
const float m2 = 0.014 ;
const float m3 = 0.011 ;
const float m23= 0.008 ;
// variables 
float Lleg = 0;
float L0 = 0 ;
float Lw = 0 ;     // effective Length (pendulum Length)

float yaw, pitch, roll;    //IMU
float yawRate, pitchRate, rollRate; //IMU

/*---MPU6050 Control/Status Variables---*/
bool DMPReady = false;  // Set true if DMP init was successful
uint8_t devStatus;      // Return status after each device operation (0 = success, !0 = error)
uint16_t packetSize;    // Expected DMP packet size (default is 42 bytes)
uint8_t FIFOBuffer[64]; // FIFO storage buffer

/*---Orientation/Motion Variables---*/ 
Quaternion q;           // [w, x, y, z]         Quaternion container
VectorInt16 gy;         // [x, y, z]            Gyro sensor measurements
VectorFloat gravity;    // [x, y, z]            Gravity vector
float ypr[3];           // [yaw, pitch, roll]   Yaw/Pitch/Roll container and gravity vector

// Encoder 
float theta_1 = 0;    // (Radian)
float theta_offset = 0;  
// Ultrasonic 
float distance = 0;

void setup() {
 
  // (I2C & Serial)
  Wire.begin();   //I2C  (IMU & Encoder)
  Wire.setClock(400000);  // 400 KHz  
  Serial.begin(115200); 

  // (Pins & Modes)(Sensors)
  as5600.begin(4);        // Encoder (pin 4)
  as5600.setDirection(AS5600_CLOCK_WISE);   // direction of increment 
  delay(500); // تأخير بسيط للتأكد من استقرار القراءة
  theta_offset = as5600.rawAngle() * AS5600_RAW_TO_RADIANS;   // Encoder Zero
  Serial.print("Encoder Zeroed at: ");
  Serial.println(theta_offset);


  HCSR04.begin(triggerPin, echoPin);      // ultrasonic
  pinMode(INTERRUPT_PIN, INPUT);          // interrupt pin of IMU

  // DMP
  Serial.println(F("Initializing DMP..."));
  mpu.initialize();
  devStatus = mpu.dmpInitialize();

  if (devStatus == 0) {
    // Calibration
    mpu.CalibrateAccel(6);
    mpu.CalibrateGyro(6);
    mpu.setDMPEnabled(true);
    //DMPDataReady
    attachInterrupt(digitalPinToInterrupt(INTERRUPT_PIN), DMPDataReady, RISING);
    DMPReady = true;    
    packetSize = mpu.dmpGetFIFOPacketSize();
    Serial.println(F("System Ready!"));
  } else {
    Serial.print(F("DMP Error: "));
    Serial.println(devStatus);
  }
}


void readIMU() {
  if (!DMPReady) return; 

  if (mpu.dmpGetCurrentFIFOPacket(FIFOBuffer)) { 
    
    // (Yaw, Pitch, Roll) angles in Radian
    mpu.dmpGetQuaternion(&q, FIFOBuffer);
    mpu.dmpGetGravity(&gravity, &q);
    mpu.dmpGetYawPitchRoll(ypr, &q, &gravity);
    
    yaw   = ypr[0]; 
    pitch = ypr[1]; 
    roll  = ypr[2];

    // (Gyro Rates) 
    mpu.dmpGetGyro(&gy, FIFOBuffer);
    // from deg/s  to  rad/s  
    yawRate   = (gy.z / 16.4) * (M_PI / 180.0);
    pitchRate = (gy.y / 16.4) * (M_PI / 180.0);
    rollRate  = (gy.x / 16.4) * (M_PI / 180.0);
    // Print 
    static unsigned long lastPrint = 0;
    if (millis() - lastPrint > 100) { 
      Serial.print("Yaw:"); Serial.print(yaw);
      Serial.print(" Pitch:"); Serial.print(pitch);
      Serial.print(" Roll:"); Serial.print(roll);
      Serial.print(" Yaw_Rate:"); Serial.print(yawRate);
      Serial.print(" Pitch_Rate:"); Serial.print(pitchRate);
      Serial.print(" Roll_Rate:"); Serial.println(rollRate);
      lastPrint = millis();
    }

  }
}
void readEncoder() {

  float currentRaw = as5600.rawAngle() * AS5600_RAW_TO_RADIANS;
  theta_1 = currentRaw - theta_offset;

}

void readUltrasonic() {
  
  double* distances = HCSR04.measureDistanceCm();
  if (distances != nullptr) {
    distance = (float)distances[0]; 
  }

  if (distance > 0 && distance < safeDistance) {
     Serial.println("Warning: Obstacle Detected!");
  }
}

void calculateKinematics() {
  
  float L5 = sqrt(pow(L2, 2) + pow(L4, 2) - 2 * L2 * L4 * cos(theta_1 + M_PI / 4.0));
  // معادلة (24): theta_2
  float theta_2 = asin((L4 * sin(theta_1 + M_PI / 4.0)) / L5);
  // معادلة (25): theta_3
  float theta_3 = acos((pow(L23, 2) + pow(L5, 2) - pow(L3, 2)) / (2 * L23 * L5));
  // معادلة (26): theta_4
  float theta_4 = M_PI - theta_1 - theta_2 - theta_3;
  // معادلة (27): Lleg الفعلي
  Lleg = L2 * sin(theta_1) + L1 * sin(theta_4);
  // معادلة (29): theta_5
  float theta_5 = M_PI - theta_4;
  // معادلة (30): theta_6
  float theta_6 = asin((L5 * sin(theta_3)) / L3) - theta_4;

  float xc2  = (L2 * sin(theta_1)) / 2.0;
  float xc1  = L2 * sin(theta_1) + (L1 * sin(theta_5)) / 2.0;
  float xc3  = -L4 * sin(M_PI / 4.0) + (L3 * sin(theta_6)) / 2.0;
  float xc23 = L2 * sin(theta_1) - (L23 * sin(theta_4)) / 2.0;
  // معادلة (35): حساب ارتفاع مركز الثقل الإجمالي L0
  L0 = (m1 * xc1 + m2 * xc2 + m3 * xc3 + m23 * xc23) / (m1 + m2 + m3 + m23);
  // معادلة (36): طول البندول الفعال Lw المستخدم في الـ LQR
  Lw = Lleg - L0;
  static unsigned long lastKinPrint = 0;
  if (millis() - lastKinPrint > 100) {
    Serial.print("Lleg: "); Serial.print(Lleg);
    Serial.print("L0: "); Serial.print(L0);
    Serial.print("Lw: "); Serial.println(Lw);
    lastKinPrint = millis();
  }
}


void loop() {
  
  readIMU();        
  readEncoder();    
  readUltrasonic(); 
  calculateKinematics(); 

}
